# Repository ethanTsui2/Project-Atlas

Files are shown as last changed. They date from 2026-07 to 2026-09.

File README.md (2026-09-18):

# Project Atlas

Project Atlas is a 5-DOF desktop robotic manipulator that I designed, 3D printed, assembled, wired, programmed, tested, and improved from scratch.

<p align="center">
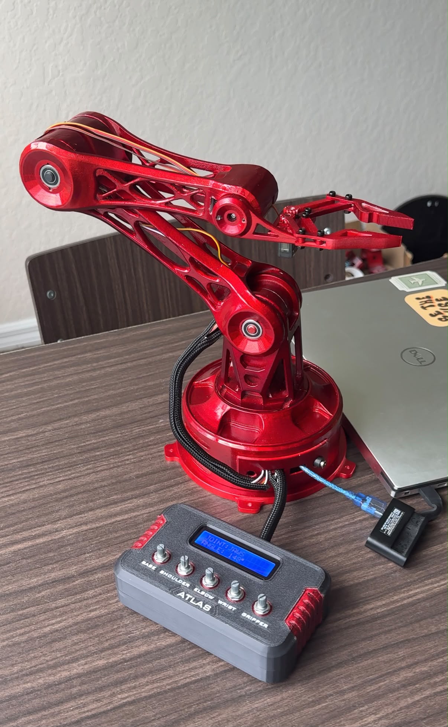
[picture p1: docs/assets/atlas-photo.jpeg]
Completed Project Atlas robotic arm
  
</p>

<p align="center">
  <a href="https://ethantsui2.github.io/Project-Atlas/"><b>Portfolio Page</b></a> |
  <a href="docs/assets/atlas-demo.mp4"><b>Demo Video</b></a> |
  <a href="CAD/"><b>CAD</b></a> |
  <a href="Documentation/Engineering-Analysis/"><b>Engineering Analysis</b></a>
</p>

---

## At a Glance

| Area | Final V1 setup |
|---|---|
| Mechanical design | SolidWorks, modular FDM-printed structure |
| Actuation | 3x MG995 + 2x MG90S servos |
| Control | Arduino Nano + PCA9685 PWM driver |
| User input | 5 potentiometers |
| User interface | 16x2 I2C LCD |
| Servo power | Regulated 5 V, 10 A external supply |
| Analysis | CAD mass properties, static torque analysis, SolidWorks FEA |
| Manufacturing | PLA FDM printing, mechanical assembly, painted finish |
| Status | **Atlas V1 prototype complete** |

## What I Worked On

- Designed the full arm layout and joint packaging in SolidWorks.
- Redesigned the upper arm, forearm, shoulder, wrist, gripper, base, and controller enclosure after physical testing.
- Added a printed slew-bearing base using **six steel balls** after the original base started tilting under load.
- Integrated five servo channels using an Arduino Nano and PCA9685.
- Built a five-potentiometer controller with a 16x2 LCD for live joint and angle feedback.
- Used CAD mass properties for a shoulder torque calculation and ran FEA on the upper arm.
- Finished the printed parts with filler primer, metallic silver, Dupli-Color Metalcast red, and gloss clear coat.

## Final Control System

The final firmware reads five potentiometers, averages eight analog readings per input, uses a 2 degree deadband to reduce unnecessary updates, drives the PCA9685 at 50 Hz, and displays the active joint angle on the LCD.

Firmware labels:

`BASE` | `ELBOW` | `WRIST` | `PIVOT` | `JAWS`

[View firmware](Firmware/)

## Engineering Highlights

### Mechanical iteration
The physical build exposed problems that were not obvious in CAD. The main ones were base tilting, forearm interference, cable pinching, servo-horn interference, wrist clearance, and gripper packaging. I went back into the CAD and changed the design around those issues instead of forcing the first version to work.

### Analysis before fabrication
Before the final build, I used SolidWorks mass properties, a static shoulder torque calculation, and a structural FEA study to check the design and better understand where the main loads were coming from.

[View engineering analysis](Documentation/Engineering-Analysis/)

### Build and integration
Atlas was built as a complete working prototype, not just a CAD model. The final system combines the printed structure, bearings, wiring, external servo power, embedded control, a separate controller enclosure, and the final painted finish.

[View build notes](Documentation/Build-Notes.md)

---

## Repository Guide

| Folder / document | What it contains |
|---|---|
| [`CAD/`](CAD/) | Final SolidWorks package, STL exports, slew-bearing files, and assembly views |
| [`Design-Evolution/`](Design-Evolution/) | The main versions of Atlas and the problems that led to each redesign |
| [`Documentation/Engineering-Analysis/`](Documentation/Engineering-Analysis/) | Torque analysis, FEA, material assumptions, and CAD mass properties |
| [`Documentation/BOM.md`](Documentation/BOM.md) | Hardware, materials, and documented project purchases |
| [`Documentation/Build-Notes.md`](Documentation/Build-Notes.md) | Manufacturing, assembly, slew bearing, electronics integration, and finishing |
| [`Electronics/`](Electronics/) | Control architecture, wiring, and pin assignments |
| [`Firmware/`](Firmware/) | Final control code and earlier development sketches |
| [`docs/`](docs/) | GitHub Pages site, resume, photo, and demo video |

## Final CAD Package

The final mechanical files are in [`CAD/Final-Package/`](CAD/Final-Package/), with the base bearing files in [`CAD/Slew-Bearing/`](CAD/Slew-Bearing/). I kept the original SolidWorks filenames so the assembly references are not broken.

[View CAD documentation](CAD/)

## Scope

Atlas V1 is a working engineering prototype. The torque calculation and FEA were design checks used during development. I have not listed payload, backlash, accuracy, or repeatability values because I did not run a controlled test for those yet.

---

## Development Process

**Requirements -> CAD -> Analysis -> 3D Printing -> Assembly -> Electronics -> Firmware -> Testing -> Redesign**

The biggest thing I learned from this project was how much changes once a design leaves CAD. Most of the useful improvements came from building it, finding what did not work, and going back to fix it.

## License

This project is released under the [MIT License](LICENSE).

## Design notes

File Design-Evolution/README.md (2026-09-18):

# Atlas V1 Design Evolution

Atlas V1 did not come from one finished CAD model. I went through several design, print, assembly, test, and redesign cycles before getting to the final version.

The main things I kept trying to improve were **joint clearance, stiffness, mass distribution, serviceability, cable routing, printability, and base stability**.

---

## Stage 1 - First Prototype

The first version proved that the basic servo-driven arm layout and gripper could work.

**Problems I found**

- bulky printed links
- limited joint clearance
- difficult servo access
- too much material in some parts
- inconsistent interfaces between components
- not enough room for cable routing

Initial Atlas V1 prototype

**What I changed:** I kept the general concept, but decided the structure needed a full redesign before I built the final version.

---

## Stage 2 - Enclosed Concept

I also tried an enclosed-shell version to hide the servos and wiring and make the arm look cleaner.

I did not continue with it because it added:

- more printed mass
- more supports
- more material
- harder assembly
- harder maintenance
- worse access to servos and fasteners

Atlas V1 enclosed-shell concept

**What I changed:** I moved away from a closed shell and focused on an open, modular structure instead.

---

## Stage 3 - Lightweight Modular Redesign

The next version used open structural rails, internal ribs, modular servo housings, split printed parts, and better access around the joints.

This improved:

- printability
- component access
- cable routing
- assembly flexibility
- mass distribution
- overall appearance

Atlas V1 lightweight modular redesign

**What I changed:** this became the main structure I used for the physical prototype.

---

## Stage 4 - Physical Test Revisions

Once I started assembling and testing the arm, I found problems that were much harder to notice in CAD.

The main ones were:

- the base tilting under the arm load
- forearm interference and restricted movement
- cable pinching
- servo-horn interference
- limited wrist and gripper clearance
- awkward access to some joints and fasteners

The biggest change was the base. I added a **printed slew bearing using six steel balls** so the rotating structure had its own mechanical support instead of relying mainly on the servo output shaft.

I also revised the forearm, servo interfaces, wiring space, and surrounding geometry after checking the real range of motion.

---

## Stage 5 - Completed Atlas V1

The final build uses:

- 3x MG995 servos for the larger arm joints
- 2x MG90S servos for the lighter end-effector functions
- printed structural links and modular housings
- a bearing-supported rotating base
- revised forearm and joint clearances
- managed cable routing
- a separate five-potentiometer controller enclosure
- a 16x2 LCD
- a metallic red painted finish

This is the final CAD assembly after the last round of physical-test revisions.

<p align="center">
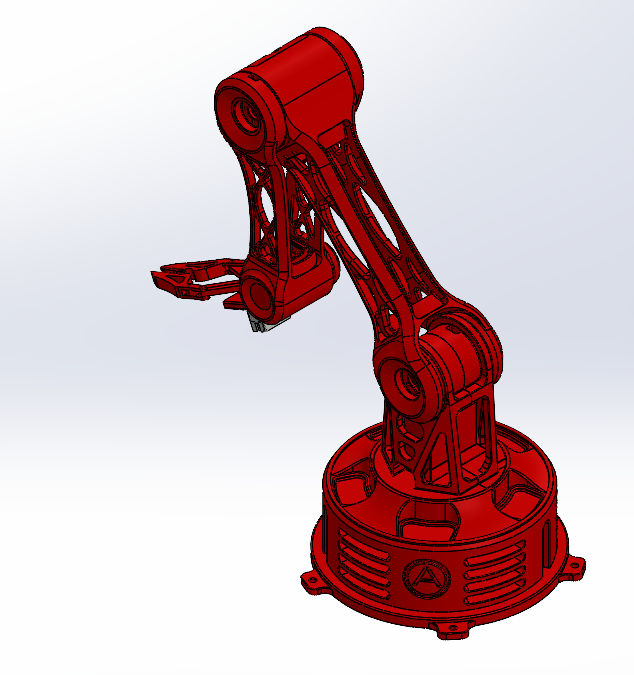
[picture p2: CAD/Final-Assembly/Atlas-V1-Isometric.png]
Final Atlas V1 CAD assembly
  
</p>

The finished physical prototype is shown below.

<p align="center">
  Completed Project Atlas V1
</p>

---

## Main Things I Learned

- Checking the full assembly matters more than checking parts one at a time.
- Weight farther from the shoulder has a much bigger effect on torque.
- Servo access, screw access, and cable routing need to be planned before printing.
- The servo shaft should not be the only structural support for a loaded rotating base.
- Physical prototypes expose tolerance, interference, stiffness, and routing problems that are easy to miss in CAD.
- A design can still look clean without adding a lot of extra material.

## Final Status

**Atlas V1 is complete as a functional physical prototype.**

I kept these earlier stages in the repo because they show how the project actually developed and why the final design looks the way it does.

For the final manufacturing and assembly details, see [Build Notes](../Documentation/Build-Notes.md).

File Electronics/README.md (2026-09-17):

# Atlas V1 Electronics

The final Atlas V1 control system uses an **Arduino Nano** to read the controls, a **PCA9685** to drive the servos, five potentiometers for manual joint control, and a **16x2 I2C LCD** for feedback.

## System Architecture

```text
5 potentiometers -> Arduino Nano -> PCA9685 -> 5 servos
                         |
                         -> I2C LCD

5 V / 10 A external supply -> PCA9685 servo rail
```

## Final Hardware

| Component | Function |
|---|---|
| Arduino Nano | Reads controls and runs the joint-control logic |
| PCA9685 | Generates PWM for five servo channels |
| 5 potentiometers | Manual joint input |
| 16x2 I2C LCD | Displays joint name and commanded angle |
| 3x MG995 | Higher-load arm joints |
| 2x MG90S | Lighter end-effector functions |
| 5 V, 10 A regulated supply | Dedicated servo power |

## Power Setup

- **Arduino Nano:** powered through USB
- **PCA9685 VCC:** 5 V logic supply from the Nano
- **PCA9685 V+:** external regulated 5 V servo supply
- **Servos:** powered from the PCA9685 V+ rail
- **Ground:** Nano, PCA9685, LCD, and external supply share a common ground

The servos are not powered directly from the Arduino Nano.

## I2C Bus

The PCA9685 and LCD share the Nano's I2C bus:

- A4 - SDA
- A5 - SCL

They use different I2C addresses, so both devices can use the same SDA and SCL lines.

## Wiring Documentation

- [Connection tables and pin assignments](wiring.md)
- [Arduino Nano / potentiometer diagram](./Arduino%20Nano%20and%20potentiometer%20wiring.png)
- [PCA9685 servo wiring diagram](./PCA9685%20servo%20wiring.png)

## Firmware

The final sketch averages the potentiometer readings, uses a 2 degree deadband, sends 50 Hz servo commands through the PCA9685, and updates the LCD when a joint command changes.

[View firmware](../Firmware/)

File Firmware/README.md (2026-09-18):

# Project Atlas Firmware

This folder contains the final Atlas V1 control sketch plus a few earlier programs I kept for reference.

## Final Control Firmware

**Location:** [`Final_Control/Atlas_Final_Control.ino`](./Final_Control/Atlas_Final_Control.ino)

The final controller uses an Arduino Nano, PCA9685 PWM driver, five potentiometers, and a 16x2 I2C LCD.

### What the final sketch does

- reads five analog control inputs
- averages **8 samples** per potentiometer reading
- maps each input to a **0-180 degree** command
- uses a **2 degree deadband** to reduce unnecessary servo updates
- drives five PCA9685 channels at **50 Hz**
- uses a pulse-width range of **650-2350 us**
- displays the active joint and angle on the LCD
- prints joint updates to the serial monitor for debugging

### Final input / channel map

| Potentiometer | Nano pin | PCA9685 channel | Firmware label |
|---|---|---|---|
| 1 | A0 | 0 | BASE |
| 2 | A1 | 1 | ELBOW |
| 3 | A2 | 2 | WRIST |
| 4 | A3 | 3 | PIVOT |
| 5 | A6 | 4 | JAWS |

## Required Arduino Libraries

- `Wire`
- `Adafruit PWM Servo Driver Library`
- `hd44780`
- `hd44780_I2Cexp`

## Development Sketches

I kept the earlier programs because they show how the controls developed from basic component testing into the final controller.

| Folder | Purpose |
|---|---|
| `basic-servo-control/` | Early PCA9685 and servo testing |
| `Manual_Control_v1/` | Earlier manual-control version |
| `Final_Control/` | Final V1 controller with averaging, deadband, and LCD feedback |

## Control Architecture

```text
Potentiometers -> Arduino Nano -> PCA9685 -> Servos
                         |
                         -> I2C LCD
```

The servos use a separate regulated 5 V supply. The Nano, PCA9685, LCD, and external supply share a common ground.

See [Electronics](../Electronics/) for the wiring and power setup.

## Scope

Atlas V1 uses direct manual joint control. It does not include closed-loop joint feedback, inverse kinematics, trajectory planning, or automatic motion sequencing.

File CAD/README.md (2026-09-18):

# Atlas V1 CAD

This folder contains the final mechanical design files for Project Atlas V1.

## Quick Access

- [`Final-Package/`](./Final-Package/) - final SolidWorks parts, assembly, and STL exports
- [`Slew-Bearing/`](./Slew-Bearing/) - printed base slew-bearing files
- [`Final-Assembly/`](./Final-Assembly/) - current CAD screenshots of the final assembly
- [`Reference_Components/`](./Reference_Components/) - servo reference geometry used in the CAD
- [`Final-CAD-Manifest.md`](./Final-CAD-Manifest.md) - file list for the final package

## Final Assembly Views

These are the most up-to-date CAD screenshots of the finished Atlas V1 assembly.

<table>
  <tr>
    <td align="center"><b>Isometric</b><br></td>
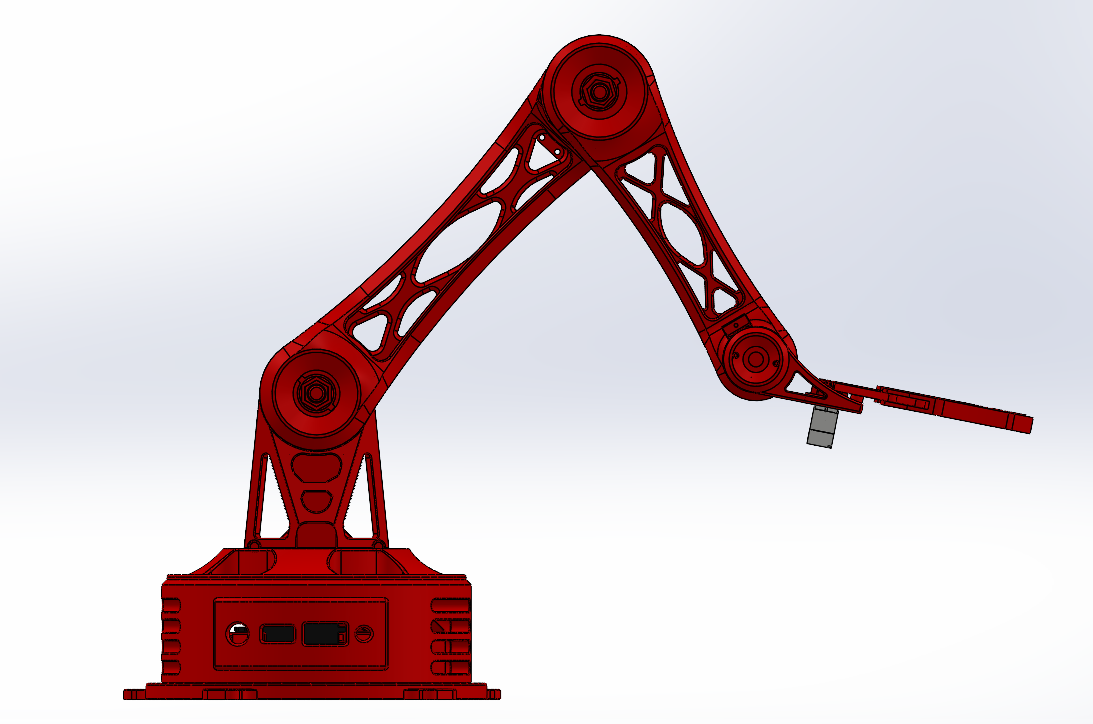
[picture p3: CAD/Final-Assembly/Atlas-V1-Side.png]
    <td align="center"><b>Side</b><br></td>
  </tr>
  <tr>
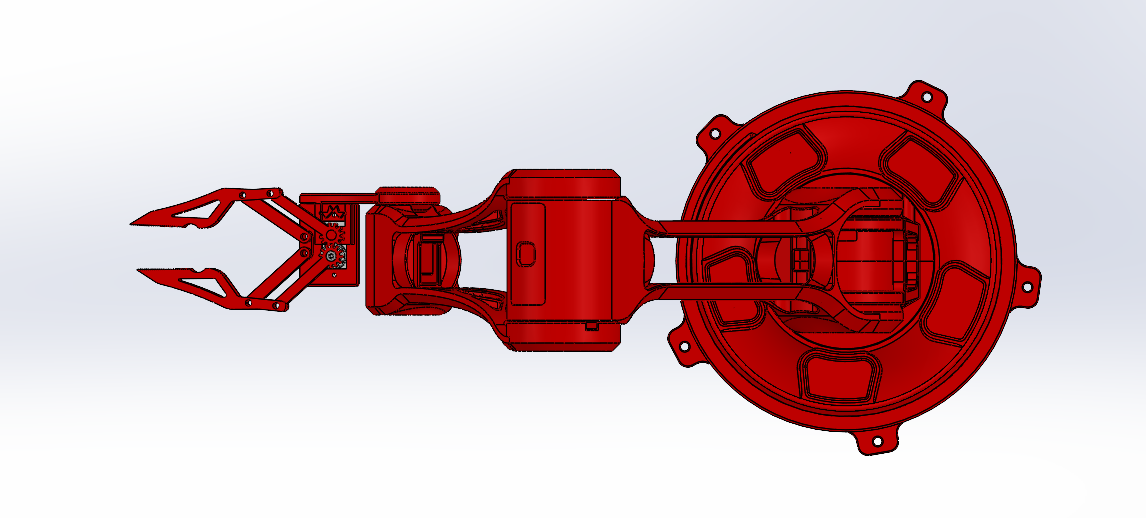
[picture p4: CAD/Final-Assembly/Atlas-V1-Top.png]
    <td align="center"><b>Top</b><br></td>
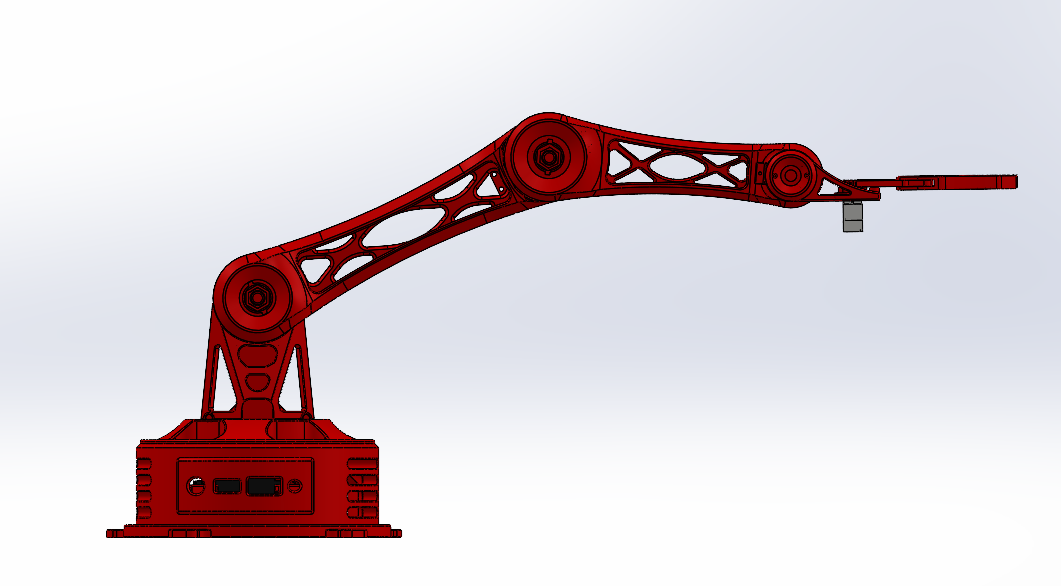
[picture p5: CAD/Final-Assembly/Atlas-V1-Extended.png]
    <td align="center"><b>Extended</b><br></td>
  </tr>
</table>

## Final Mechanical Setup

| Subsystem | Final approach |
|---|---|
| Base | Printed housing with six-ball slew-bearing support |
| Shoulder / main joints | MG995-driven modular printed structure |
| Upper arm | Lightweight ribbed PLA link |
| Forearm | Revised printed forearm with more clearance and routing space |
| Wrist / gripper | MG90S-driven end-effector assembly |
| Controller | Separate printed enclosure for five potentiometers and a 16x2 LCD |
| Manufacturing | SolidWorks source files with STL exports for printed parts |

## Final CAD Package

The final CAD is stored in [`Final-Package/`](./Final-Package/). This is the version that matches the completed build and includes the arm links, shoulder mounts, base housing, wrist and gripper parts, bearing interfaces, and controller enclosure.

The separate [`Slew-Bearing/`](./Slew-Bearing/) folder contains the base bearing geometry. The finished bearing uses **six steel balls**.

I kept the original SolidWorks filenames because renaming referenced parts outside SolidWorks can break the assembly.

## Main Design Priorities

The final design focused on:

- joint clearance
- reducing printed mass without making the links too flexible
- access to servos and fasteners
- better base support
- cable-routing space
- parts that could be printed separately and replaced if needed
- keeping the mechanical style consistent across the arm

For the main redesigns and the problems that caused them, see [Design Evolution](../Design-Evolution/README.md).

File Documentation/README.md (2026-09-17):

# Project Atlas Documentation

This folder contains the supporting engineering documentation for the completed Atlas V1 prototype.

I split the documentation into a few focused sections so it is easy to skim, but the technical details are still there if someone wants to go deeper.

## Documentation Map

| Document | What it covers |
|---|---|
| [Engineering Analysis](./Engineering-Analysis/README.md) | Material assumptions, CAD mass properties, shoulder torque, and upper-arm FEA |
| [Bill of Materials](./BOM.md) | Hardware, materials, and documented project purchases |
| [Build Notes](./Build-Notes.md) | Manufacturing, assembly, slew-bearing redesign, controller, wiring, and surface finishing |

## Related Project Sections

- [CAD](../CAD/) - final mechanical files and assembly views
- [Design Evolution](../Design-Evolution/) - the major versions and problems that led to redesigns
- [Electronics](../Electronics/) - control architecture and wiring
- [Firmware](../Firmware/) - final control code and earlier test sketches
- [Portfolio Site](https://ethantsui2.github.io/Project-Atlas/) - quick overview, resume, photo, and demo video

I left out generic workshop tools and other routine items unless they directly affected the design or build.

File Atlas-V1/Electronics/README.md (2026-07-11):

## Electronics Architecture

The robotic arm uses an Arduino Nano to read five potentiometers. Servo commands are sent through I2C to a PCA9685 16-channel PWM controller.

The Arduino Nano handles logic and input processing, while a separate regulated 5 V, 10 A supply powers the servos. All grounds are connected together to provide a shared voltage reference.

### Signal Flow

Potentiometers → Arduino Nano analog inputs → I2C → PCA9685 → Servos

### Important Power Separation

- Arduino Nano: powered through USB
- PCA9685 VCC: powered by the Nano 5 V output
- PCA9685 V+: powered by the external 5 V supply
- Servos: powered only through the PCA9685 V+ servo rail
- Nano, PCA9685, and external supply share a common ground

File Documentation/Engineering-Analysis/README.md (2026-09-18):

# Atlas V1 Engineering Analysis

I completed these analyses before the final Atlas V1 build to check the main mechanical loads and make better design decisions before printing everything.

They are design checks, not certified performance ratings for the finished robot.

## Analysis Baseline

All of the analysis was done using a frozen copy of the Atlas V1 CAD assembly.

| Property | Value |
|---|---|
| Revision | Atlas V1 Analysis Baseline |
| CAD Software | SolidWorks |
| Printed Material | Anycubic PLA V3.0 |
| Purpose | Check material properties, mass properties, shoulder torque, and upper-arm structural behavior before manufacturing |

## Analysis Configuration

For the shoulder torque calculation, I used the maximum practical extension I could reach before collision in SolidWorks. I chose that position because it gave the largest practical moment arm in the analyzed geometry.

---

## 1. Material Assumptions

I created a custom SolidWorks material using values from the **Anycubic PLA V3.0 Technical Data Sheet**.

The material documentation includes:

- density
- elastic modulus
- Poisson's ratio
- strength properties
- modeling assumptions
- density verification

[View material assumptions](./Material-Assumptions.md)

---

## 2. CAD Mass Properties

I extracted mass, volume, and center-of-mass data from SolidWorks for the main modeled components.

[View mass-property inventory](./Mass-Properties.md)

---

## 3. Static Shoulder Torque Analysis

I used the CAD mass properties and a static moment calculation to estimate the shoulder torque requirement.

### Key Results

| Quantity | Value |
|---|---:|
| Required shoulder torque | **1.047 N·m (10.67 kg·cm)** |
| Deegoo-FPV MG995 specified stall torque at 6 V | **13.00 kg·cm** |
| Static utilization | **82.1%** |
| Remaining static torque margin | **17.9%** |

Based on this calculation, the MG995 was theoretically capable of holding the analyzed configuration under static loading with no external payload.

This calculation did not include dynamic loading, acceleration, friction, wiring, fasteners, manufacturing tolerances, or payload effects.

[View full torque report](./Atlas-V1-Static-Shoulder-Torque-Analysis.pdf)

---

## 4. Upper-Arm Static Structural FEA

I also ran a static structural study on the upper arm in SolidWorks Simulation.

### Key Results

| Quantity | Value |
|---|---:|
| Maximum von Mises stress | **25.31 MPa** |
| Maximum resultant displacement | **0.755 mm** |
| Maximum equivalent strain | **0.00450** |
| Critical stress region | **Shoulder mounting bore** |
| Nominal X-Y strength ratio | **1.90** |
| Nominal Z-direction strength ratio | **1.11** |

For the model, I fully constrained the shoulder mounting bore. The real joint has additional bearing and support structure, so I treated the FEA as a conservative design check instead of an exact prediction of the assembled arm.

[View full FEA report](./Atlas-V1-Link1-Static-Structural-Analysis.pdf)

---

## After the Analysis

After building Atlas, physical testing led to more changes around the base support, joint clearance, wiring, and packaging.

I kept the original analysis in the repo because it shows the reasoning I used before fabrication. Any future payload, backlash, accuracy, or repeatability numbers should come from physical testing rather than being estimated from these reports.

[Return to project overview](../../README.md)

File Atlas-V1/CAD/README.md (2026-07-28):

# Atlas V1 CAD

This folder contains the complete mechanical CAD design for **Project Atlas V1**, including the final assembly, reference components, and design resources used throughout development.

---

# Final Assembly

The current mechanical design is shown below.

## Isometric View

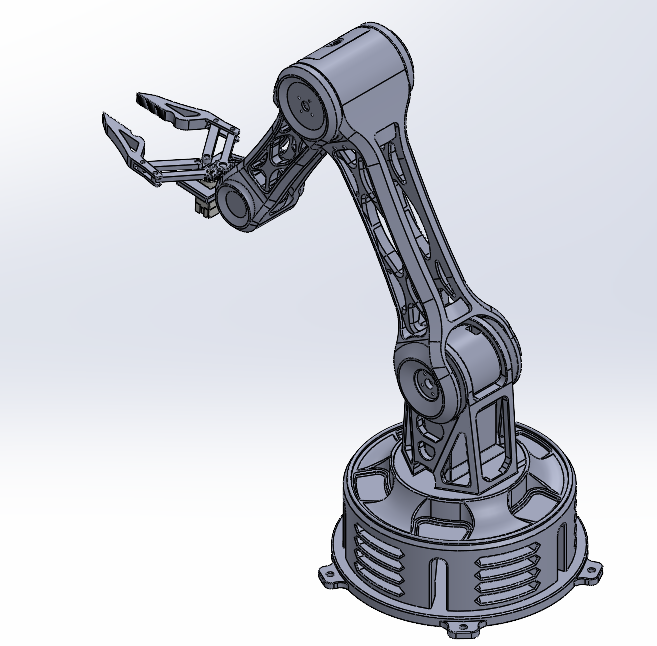
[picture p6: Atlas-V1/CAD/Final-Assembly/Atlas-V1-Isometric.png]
Atlas V1 Isometric


---

## Side View

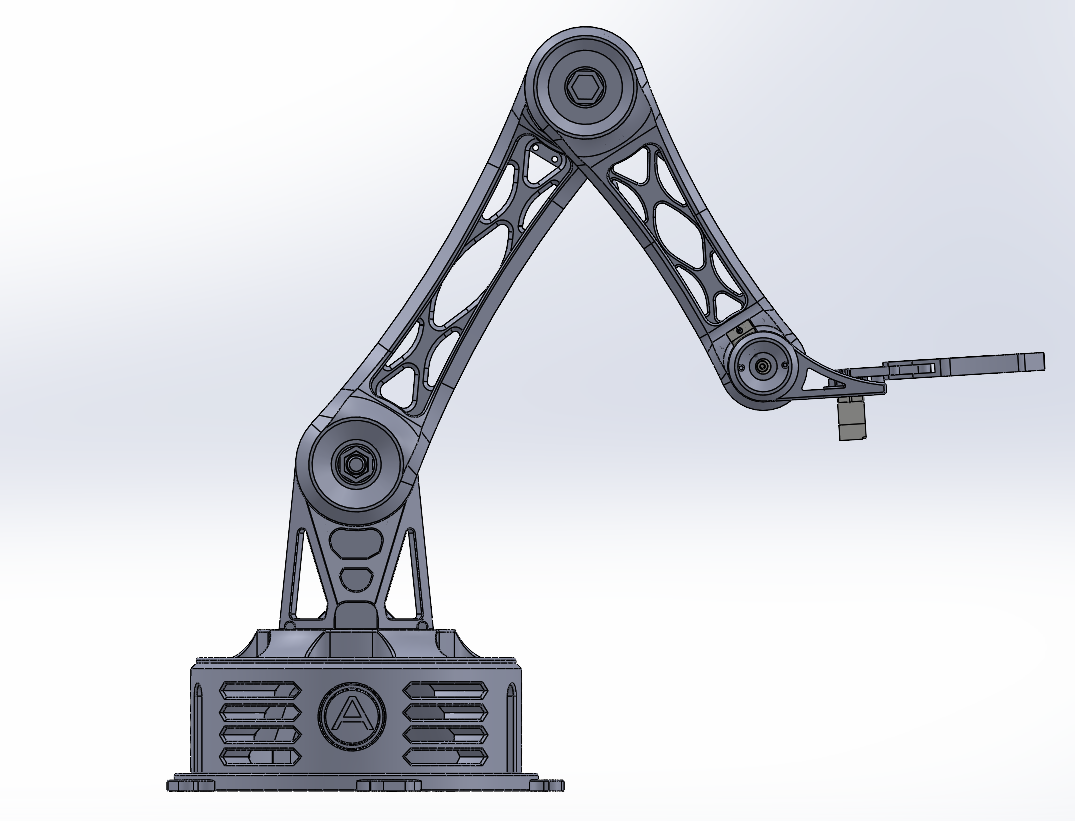
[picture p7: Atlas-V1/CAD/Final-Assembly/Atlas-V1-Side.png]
Atlas V1 Side


---

## Top View

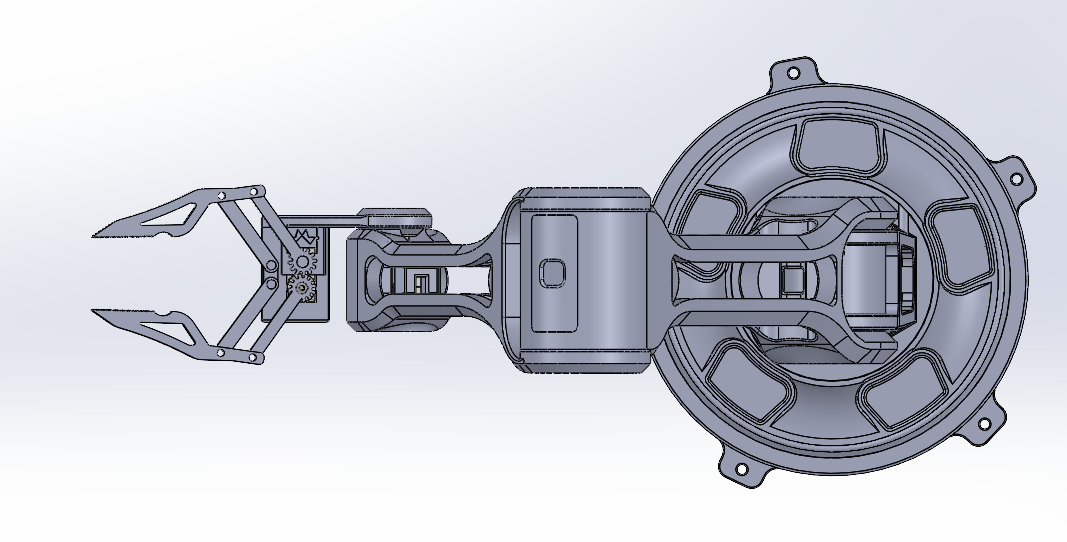
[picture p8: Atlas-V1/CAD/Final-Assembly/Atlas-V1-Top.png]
Atlas V1 Top


---

## Extended Configuration

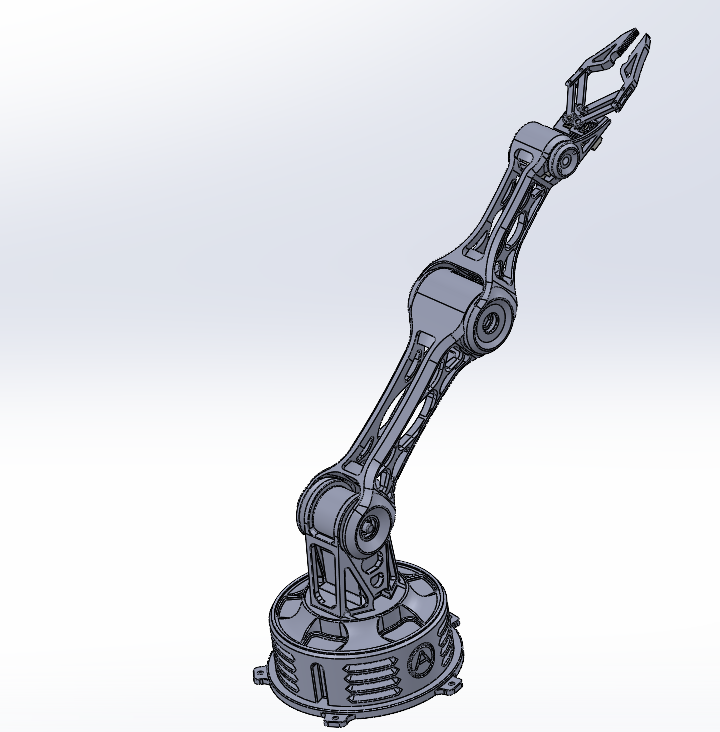
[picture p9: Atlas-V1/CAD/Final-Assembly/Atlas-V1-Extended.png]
Atlas V1 Folded


---

# Mechanical Specifications

| Component | Description |
|---|---|
| Degrees of Freedom | 5 DOF |
| Base Servo | MG995 |
| Shoulder Servo | MG995 |
| Elbow Servo | MG995 |
| Wrist Servo | MG90S |
| Gripper Servo | MG90S |
| CAD Software | SolidWorks |
| Manufacturing | FDM 3D Printing |

---

# Design Features

- Lightweight ribbed arm links
- Modular servo housings
- Split-print construction
- Internal cable routing
- Collision-checked assembly
- Heat-set insert mounting
- Serviceable servo covers
- Modular gripper assembly

---

# Folder Contents

```text
CAD/
├── Final-Assembly/
│   └── Final CAD screenshots
├── Source-Files/
│   └── Native SolidWorks parts and assemblies
├── Reference_Components/
│   ├── MG995/
│   └── MG90S/
└── README.md
│
└── README.md
```

```markdown
## Source Files

The `Source-Files` directory contains the complete SolidWorks assembly and its referenced components.

The files were exported using SolidWorks Pack and Go to preserve assembly references and reduce the chance of missing-part errors.

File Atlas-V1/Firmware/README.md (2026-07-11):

# Firmware

This folder contains the Arduino firmware developed for Project Atlas.

## Current Sketch

### Basic Servo Control

Location:

`basic-servo-control/basic-servo-control.ino`

This sketch was used to validate the initial electronics system.

It:

- Reads five potentiometers using the Arduino Nano
- Sends servo commands to the PCA9685 over I2C
- Controls five servo channels
- Maps potentiometer readings to servo angles from 0° to 180°
- Uses an external 5 V power supply for the servos

## Required Arduino Libraries

- Wire
- Adafruit PWM Servo Driver Library

## Hardware

- Arduino Nano
- PCA9685 16-channel PWM controller
- Five potentiometers
- Five servos
- External regulated 5 V power supply

## Current Status

The basic manual control system has been tested successfully.

## Planned Improvements

- Add joint-specific angle limits
- Add servo calibration offsets
- Add smoother motion
- Reduce sudden movement
- Add startup positioning
- Add emergency-stop behavior

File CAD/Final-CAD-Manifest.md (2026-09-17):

# Atlas V1 Final CAD Package Manifest

This is the file list for the final Atlas V1 CAD package. I kept the original filenames so the SolidWorks references are not broken.

## Repository Locations

- [`Final-Package/`](./Final-Package/) - main Atlas SolidWorks package and STL exports
- [`Slew-Bearing/`](./Slew-Bearing/) - final base slew-bearing files

## Main Atlas Package

### Assembly

- `v3 assembly.SLDASM`

### Major arm / base parts

- `AJM-01  → Atlas Joint Module (MG995)final.SLDPRT`
- `Atlas-V1-Upper-Arm.SLDPRT`
- `Atlas-V1-Upper-Arm.STL`
- `Atlas-V1-Forearm edit v2.SLDPRT`
- `Atlas-V1-Forearm edit v2.STL`
- `Atlas-V1-Shoulder-Mount-Left.SLDPRT`
- `Atlas-V1-Shoulder-Mount-Left.STL`
- `Atlas-V1-Shoulder-Mount-Right.SLDPRT`
- `Atlas-V1-Shoulder-Mount-Right.STL`
- `Atlas-V1-Base-Housing top.SLDPRT.SLDPRT`
- `Atlas-V1-Base-Housing top.STL`
- `Atlas-V1-Base-Housing bottom.SLDPRT.SLDPRT`
- `Atlas-V1-Base-Housing bottom.STL`
- `base housing.SLDPRT`

### Bearing / servo interface parts

- `bearing holder.SLDPRT`
- `bearing holder.STL`
- `bearing holder2.SLDPRT`
- `bearing holder2.STL`
- `bearing holder link 2.SLDPRT`
- `circular servo horn.SLDPRT`
- `servo horn extender.SLDPRT`
- `servo horn extender.STL`
- `servo lid.SLDPRT`
- `servo lid.STL`

### Gripper / wrist parts

- `gripper gear link.SLDPRT`
- `gripper gear link.STL`
- `gripper gear link2.SLDPRT`
- `gripper gear link2.STL`
- `gripper jaw.SLDPRT`
- `gripper jaw.STL`
- `gripper link1.SLDPRT`
- `gripper link1.STL`
- `robotic gripper part.SLDPRT`
- `robotic gripper wrist.SLDPRT`
- `robotic gripper wrist.STL`

### Controller parts

- `control board.SLDPRT`
- `control pannel.SLDPRT`
- `control pannel.STL`
- `controller bottom.SLDPRT`
- `controller bottom.STL`
- `controller top.SLDPRT`
- `controller top.STL`

## Slew-Bearing Package

- `Outer Race.f3d`
- `Outer Race.stl`
- `Inner Race.stl`
- `Upper Inner Race.stl`
- `Lower Inner Race.stl`
- `Cage.stl`
- `Parametric+Slew+Bearing+v9.stl`

The finished base bearing uses **six steel balls**.

## File Handling Note

The final package is kept together with the original filenames. Renaming SolidWorks parts outside SolidWorks can break assembly references.

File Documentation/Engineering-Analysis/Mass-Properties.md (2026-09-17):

# Atlas V1 Mass Inventory

This table records the mass properties I pulled directly from SolidWorks for the main Atlas V1 components.

The values are based on the CAD model using the verified **Anycubic PLA V3.0** material. I used this data as the starting point for the center-of-mass, torque, and FEA work.

| Component | Material | Mass (g) | Volume (mm³) | COM X (mm) | COM Y (mm) | COM Z (mm) | Evidence |
|:---|:---:|---:|---:|---:|---:|---:|:---:|
| **Printed Components** |||||||||
| Base Housing | PLA | 664.33 | 535753.64 | -0.54 | 19.66 | 0.56 | [View](Images/Base-Housing-Mass-Properties.png) |
| Shoulder Structure | PLA |196.29 |158294.43 |0.00 |40.84 |-0.06 | [View](Images/Wrist-Structure-Mass-Properties.png)|
| Link 1 Structure | PLA | 283.81 | 228876.24 | 582.93 | 991.96 | 1316.60 | [View](Images/Link-1-Mass-Properties.png) |
| Link 2 Structure | PLA | 164.24 | 132452.17 | 0.00 | 72.44 | -34.82 | [View](Images/Link-2-Mass-Properties.png) |
| Complete End Effector | PLA |30.23 |24378.13 |410.32 | 894.39|1307.39 |[View](Images/End-Effector-Mass-Properties.png)|
| **Purchased Components** |||||||||
| Shoulder MG995 Servo | Manufacturer | 55 | | | | | |
| Elbow MG995 Servo | Manufacturer | 55 | | | | | |
| Wrist MG90S Servo | Manufacturer | 13.4 | | | | | |
| Gripper MG90S Servo | Manufacturer | 13.4 | | | | | |
| **Estimated Components** |||||||||
| Fasteners & Heat-Set Inserts | Steel / Brass | | | | | | |
| Wiring | Copper / PVC | | | | | | |
| Payload (Design Target) | Variable | | | | | | |

> **Note:** Printed component values came from SolidWorks using the verified Anycubic PLA material. Servo masses are based on manufacturer specifications.

## Mass Summary

| Category | Mass (g) |
|---|---:|
| Printed Components | **1338.90** |
| Servos | **136.80** |
| Estimated Hardware | - |
| Estimated Wiring | - |
| **Estimated Total Robot Mass** | **1475.70 + hardware** |

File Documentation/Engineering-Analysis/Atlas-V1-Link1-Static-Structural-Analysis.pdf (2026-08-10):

Atlas V1 Finite Element Analysis

Upper Arm (Link 1) — Conservative Static Structural Assessment

Project Atlas | SolidWorks Simulation | August 2026

### 1. Objective

A finite element analysis (FEA) was performed on the Atlas V1 upper arm (Link 1) using SolidWorks

Simulation. The purpose of the analysis was to evaluate the structural response of the 3D-printed component

under representative static loading and identify regions of elevated stress and deformation.

The analysis focused on:

- Von Mises stress
- Resultant displacement
- Equivalent strain
- Critical stress locations
- Influence of the shoulder support condition

The analysis uses a simplified conservative support configuration in which the shoulder mounting bore is fully

constrained. In the physical Atlas V1 assembly, the opposite side of the shoulder joint is additionally supported

by a bearing. This bearing support was intentionally excluded from the FEA model to maintain a simplified

conservative structural assessment.

### 2. Material Properties

The upper arm is designed to be manufactured from Anycubic PLA using fused-filament fabrication.

Material properties were obtained from the Anycubic PLA Technical Data Sheet, Version 3.0. The manufacturer

reports properties based on printed test specimens and notes that mechanical performance depends on print

orientation and processing conditions.

Property | Value
Density | 1.24 g/cm³
Young's Modulus (X-Y) | 2534 ± 85 MPa
Tensile Strength (X-Y) | 48 ± 5 MPa
Tensile Strength (Z) | 28 ± 2.4 MPa
Elongation at Break (X-Y) | 8 ± 1%
Bending Strength (X-Y) | 90 ± 3 MPa
Bending Modulus (X-Y) | 3360 ± 100 MPa

The SolidWorks Simulation model approximates the printed PLA component as a homogeneous material.

Actual FDM-printed PLA exhibits direction-dependent mechanical behavior due to layer orientation and

interlayer bonding. Therefore, the simulation results are treated as a first-order structural estimate rather than an

exact prediction of printed-part failure.

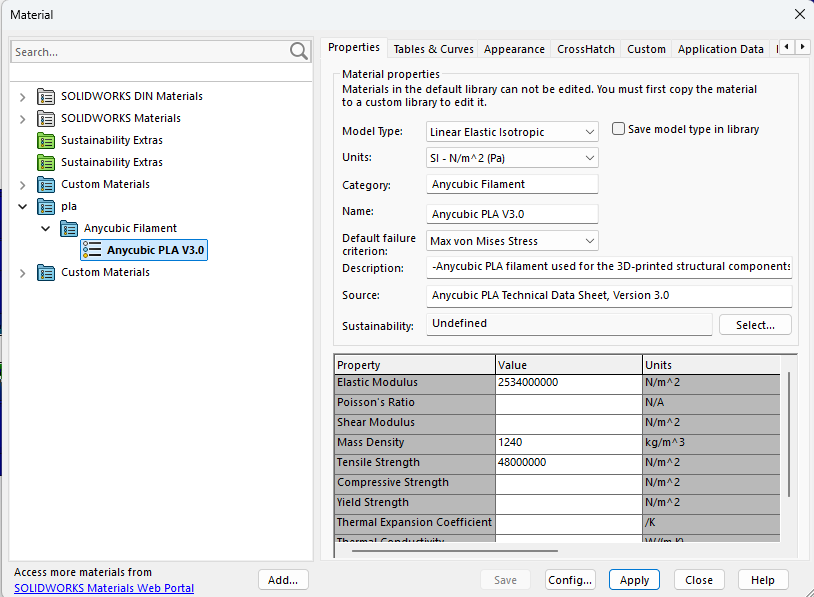
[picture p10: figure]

Figure 1: Anycubic PLA V3.0 Material Properties

### 3. Link 1 Static Structural Analysis

### 3.1 Analysis Configuration

A static structural study was created in SolidWorks Simulation to evaluate Link 1 under the loads transferred

from the downstream arm components.

The analysis represents the loading condition developed from the previously completed Atlas V1 static shoulder

torque analysis.

For the initial conservative study, the shoulder mounting bore was fully constrained. This simplifies the actual

joint connection and intentionally does not account for the additional support provided by the bearing located on

the opposite side of the assembled shoulder joint.

As a result, this study represents a simplified conservative structural model of Link 1. The actual assembly

includes additional bearing support at the shoulder joint; therefore, the boundary conditions used in this study

do not attempt to reproduce the complete joint contact behavior.

Applied Boundary Conditions

Boundary Condition | Value / Description
Study type | Static structural
Material | Anycubic PLA V3.0
Shoulder support | Fixed mounting bore
Gravity | 9.81 m/s²
Applied downstream force | 2.71 N
Applied moment | 0.221 N·m

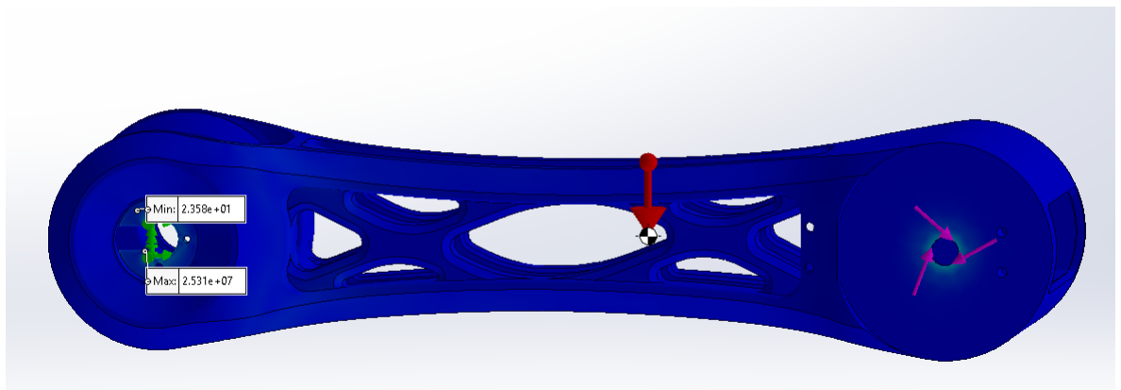
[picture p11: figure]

Figure 2: Conservative FEA Boundary Conditions

### 3.2 Mesh

A solid finite-element mesh was generated across the Link 1 geometry. The mesh captures the lightweight rib

structure, joint interfaces, mounting holes, fillets, and other geometric features that may influence the stress

distribution.

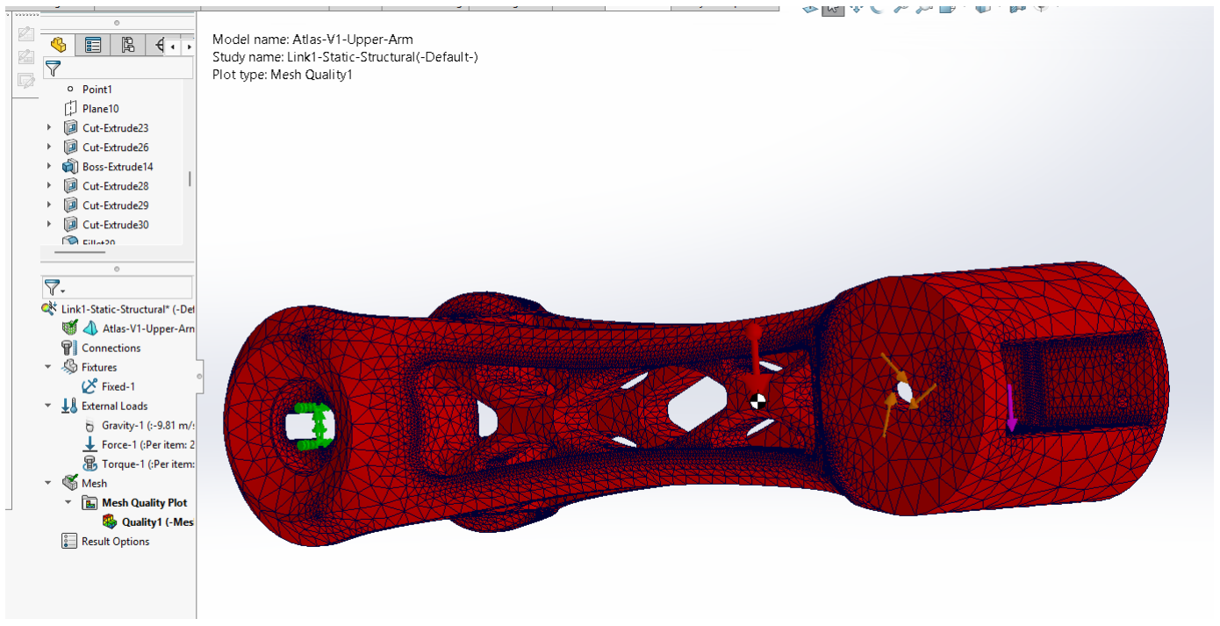
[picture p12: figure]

Figure 3: Link 1 Finite Element Mesh

A solid finite-element mesh was used to discretize the Link 1 geometry. The mesh was refined automatically

around smaller geometric features, fillets, mounting holes, and the lightweight rib structure. The resulting mesh

was considered sufficient for this preliminary structural assessment.

### 4. Conservative Analysis Results

### 4.1 Von Mises Stress

The static simulation predicted a maximum von Mises stress of 25.31 MPa. The maximum stress occurs locally

near the constrained shoulder mounting bore, where the applied loading is reacted through the fixed boundary

condition. Most of the upper-arm structure experiences substantially lower stress, indicating that the predicted

peak is localized around the shoulder connection rather than distributed throughout the lightweight rib structure.

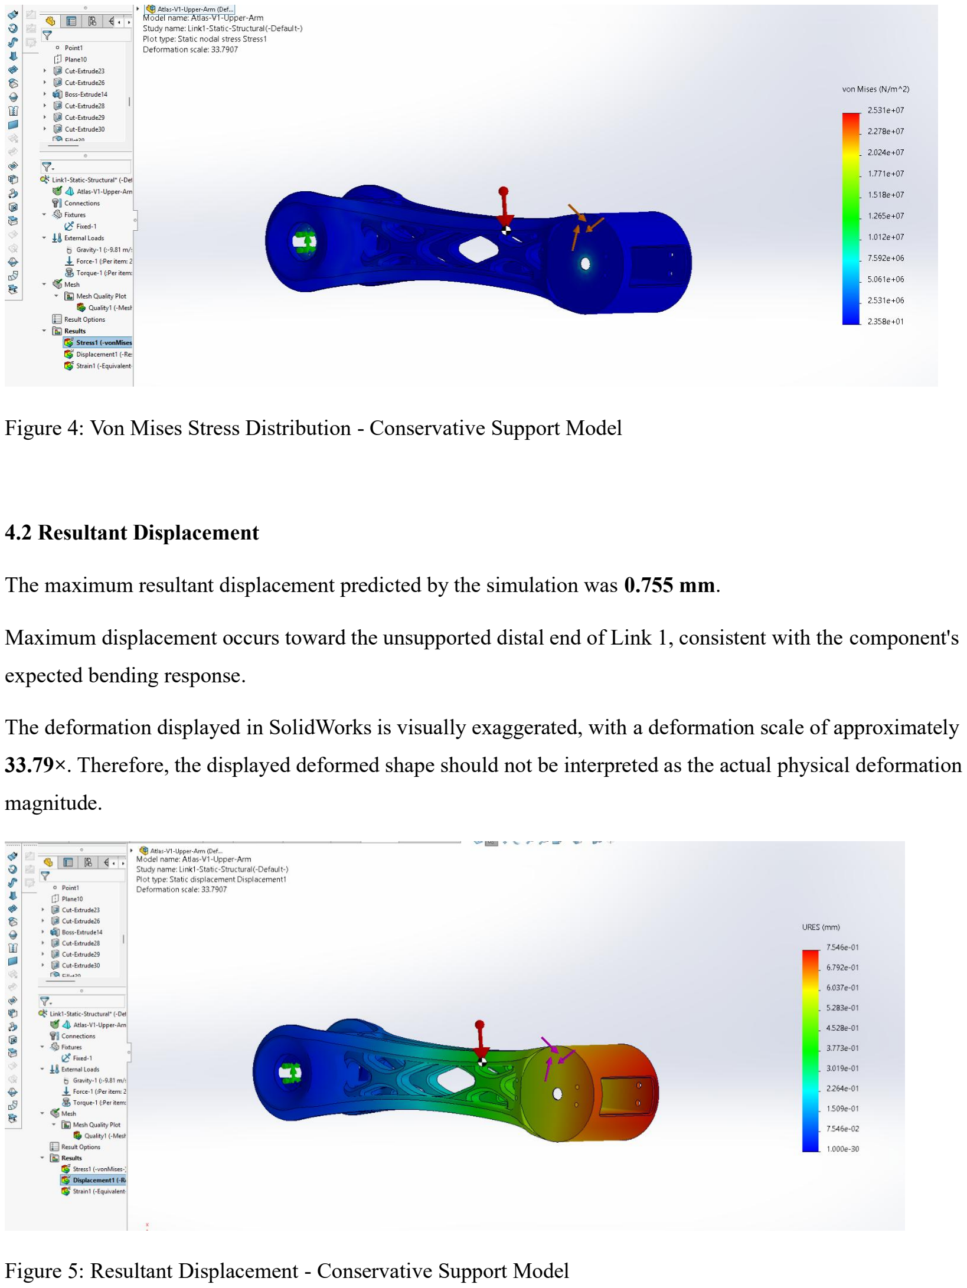
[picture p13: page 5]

Figure 4: Von Mises Stress Distribution - Conservative Support Model

### 4.2 Resultant Displacement

The maximum resultant displacement predicted by the simulation was 0.755 mm.

Maximum displacement occurs toward the unsupported distal end of Link 1, consistent with the component's

expected bending response.

The deformation displayed in SolidWorks is visually exaggerated, with a deformation scale of approximately

33.79×. Therefore, the displayed deformed shape should not be interpreted as the actual physical deformation

magnitude.

Figure 5: Resultant Displacement - Conservative Support Model

### 4.3 Equivalent Strain

The maximum equivalent strain predicted by the model was approximately 0.00450.

The strain distribution follows the general stress response of the structure, with elevated values concentrated

near the constrained joint region.

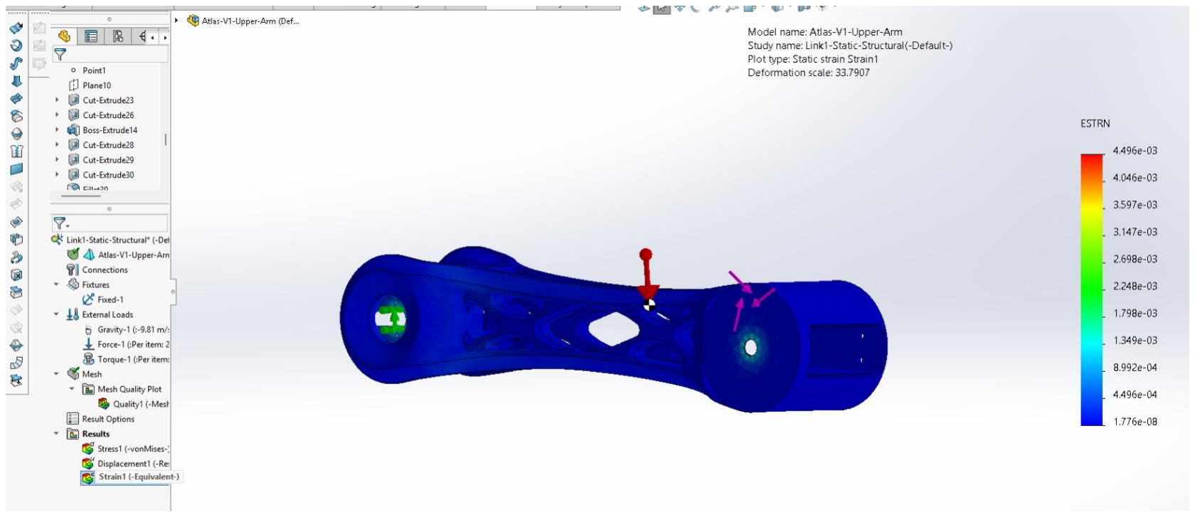
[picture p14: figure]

Figure 6: Equivalent Strain - Conservative Support Model

### 5. Conservative Analysis Summary

Result | Conservative Model
Maximum von Mises stress | 25.31 MPa
Maximum resultant displacement | 0.755 mm
Maximum equivalent strain | 0.00450
Critical stress region | Shoulder mounting bore
X-Y tensile strength | 48 ± 5 MPa
Nominal tensile-strength ratio | 1.90
Z-direction tensile strength | 28 ± 2.4 MPa
Nominal Z-direction strength ratio | 1.11

### 5.1 Nominal Tensile-Strength-to-Stress Ratio

Using the manufacturer's typical X-Y tensile strength:

X-Y Tensile Strength = 48 MPa

Maximum von Mises Stress = 25.31 MPa

The nominal tensile-strength-to-stress ratio was calculated as:

Strength Ratio = Tensile Strength / Maximum von Mises Stress

Strength Ratio = 48 MPa / 25.31 MPa

Strength Ratio = 1.90

Therefore, the nominal X-Y tensile-strength-to-stress ratio for the conservative simulation is approximately

1.90.

This value is not reported as a conventional yield-based factor of safety because the Anycubic PLA V3.0

technical data sheet does not provide a material yield strength. Additionally, the manufacturer's reported tensile

properties are dependent on print orientation and processing conditions.

### 5.2 Z-Direction Strength Consideration

The manufacturer reports a lower Z-direction tensile strength of:

Z-Direction Tensile Strength = 28 MPa

For comparison, the nominal Z-direction tensile-strength-to-stress ratio was calculated as:

Strength Ratio (Z) = Z-Direction Tensile Strength / Maximum von Mises Stress

Strength Ratio (Z) = 28 MPa / 25.31 MPa

Strength Ratio (Z) = 1.11

The resulting nominal Z-direction strength-to-stress ratio is approximately 1.11.

This value should not be interpreted as a conventional factor of safety because the SolidWorks model

approximates the printed PLA as a homogeneous isotropic material and does not explicitly model FDM layer

orientation or interlayer bonding.

However, the relatively small Z-direction strength ratio indicates that print orientation is an important

manufacturing consideration for Link 1. The component should therefore be printed in an orientation that

minimizes critical structural loading across the weaker interlayer direction where practical.

### 6. Conclusion

A static finite element analysis was performed on the Atlas V1 upper arm (Link 1) to evaluate its structural

response under representative loading derived from the Atlas V1 shoulder loading analysis.

The conservative model predicted a maximum von Mises stress of 25.31 MPa, a maximum resultant

displacement of 0.755 mm, and a maximum equivalent strain of approximately 0.00450. The highest predicted

stress was localized near the constrained shoulder mounting bore, while the majority of the lightweight rib

structure experienced substantially lower stress.

Comparison with the manufacturer's typical X-Y tensile strength of 48 MPa produced a nominal tensile-

strength-to-stress ratio of approximately 1.90. Comparison with the manufacturer's typical Z-direction tensile

strength of 28 MPa produced a lower nominal ratio of approximately 1.11, highlighting the importance of print

orientation for the FDM-manufactured component.

The analysis contains several simplifying assumptions. The printed PLA was modeled as a homogeneous,

linear-elastic, isotropic material, whereas actual FDM-printed PLA exhibits direction-dependent mechanical

behavior. The shoulder mounting bore was also modeled as fully constrained, while the physical Atlas V1

shoulder assembly includes additional bearing support on the opposite side of the joint. Dynamic loading,

impact, fastener preload, joint clearance, manufacturing defects, and detailed layer adhesion were not explicitly

modeled.

Within these assumptions, the conservative static analysis indicates that the Link 1 geometry is suitable to

proceed to prototype fabrication and physical validation. Final structural performance will be evaluated

through testing of the manufactured Atlas V1 assembly.

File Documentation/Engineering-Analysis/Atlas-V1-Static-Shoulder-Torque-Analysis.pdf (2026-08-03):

Atlas V1 Static Torque Analysis

### 1. Objective

The objective of this analysis is to determine whether the selected MG995 shoulder servo can statically support

the Atlas V1 robotic arm under its maximum collision-limited extension. The required shoulder holding torque

is calculated using SolidWorks mass properties and compared against the manufacturer's specified stall torque.

The analysis estimates the torque required at both the shoulder and elbow joints when the arm is positioned at

its maximum practical extension (collision-limited configuration). The calculated torque will then be compared

to the manufacturer's rated torque of the MG995 servo.

### 2. Assumptions

The following assumptions are made:

- Static analysis only (no acceleration).
- Gravity acts vertically downward.
- All printed components are modeled using Anycubic PLA V3.0 material.
- CAD mass properties obtained from SolidWorks are assumed accurate.
- Servo masses are taken from manufacturer specifications.
- Wiring, screws, bearings, and payload are neglected during the initial analysis.
- The arm configuration corresponds to the maximum extension achievable before self-collision.

### 3. Component Masses

Component | Mass (g) | Mass (kg)
Link 1 Printed Structure | 280.24 | 0.28024
Elbow MG995 Servo | 55 | 0.05500
Link 2 Printed Structure | 164.24 | 0.16424
Wrist MG90S Servo | 13.4 | 0.01340
Printed End Effector | 30.23 | 0.03023
Gripper MG90S Servo | 13.4 | 0.01340

### 4. Weight Calculation

Each component weight is calculated using

W = mg

where

- m= component mass (kg)
- g = 9.81 m/s

2

Weight Calculations

Link 1

W1 = 0.28024(9.81)

W1 = 2.749N

Elbow Servo

W2 = 0.055(9.81)

W2 = 0.540N

Link 2

W3 = 0.16424(9.81)

W3 = 1.611N

Wrist Servo

W4 = 0.0134(9.81)

W4 = 0.131N

Printed End Effector

W5 = 0.03023(9.81)

W5 = 0.297N

Gripper Servo

W6 = 0.0134(9.81)

W6 = 0.131N

Summary

Component | Mass (g) | Mass (kg)
Link 1 Printed Structure | 280.24 | 0.28024
Elbow MG995 Servo | 55 | 0.05500
Link 2 Printed Structure | 164.24 | 0.16424
Wrist MG90S Servo | 13.4 | 0.01340
Printed End Effector | 30.23 | 0.03023
Gripper MG90S Servo | 13.4 | 0.01340

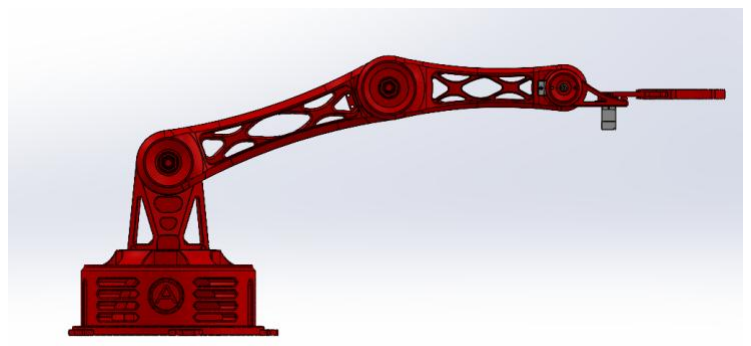
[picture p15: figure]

Figure 1: Fully Extended Arm

Figure 1 illustrates the loading assumptions used for the static analysis. Each component weight is represented

as a concentrated force acting through its center of mass.

FBD

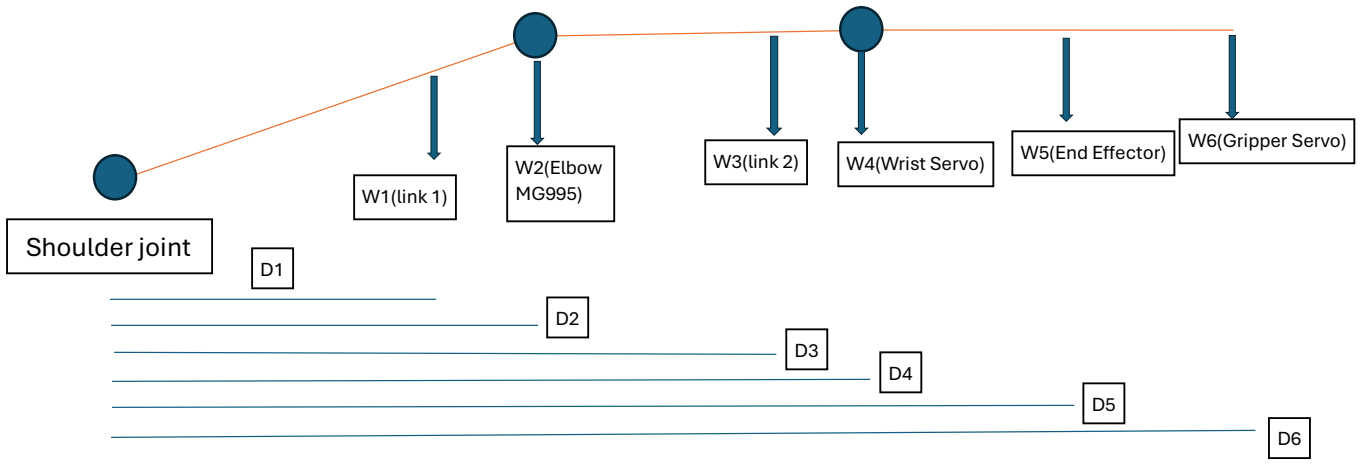
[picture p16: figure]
Shoulder joint; W1(link 1); W2(Elbow MG995); W3(link 2); W4(Wrist Servo); W5(End Effector); W6(Gripper Servo)

### 5. Determination of Moment Arms

The torque generated by each component depends on both its weight and the perpendicular distance from the

shoulder joint to its center of mass. These distances were determined directly from the SolidWorks assembly

using the maximum collision-limited extension of the Atlas V1 arm.

Each printed component was assigned the verified Anycubic PLA V3.0 material and its center of mass was

obtained using the SolidWorks Mass Properties tool. Manufacturer specifications were used for the servo

masses, while their center locations were approximated at the geometric centers of the servo bodies.

The maximum collision-limited extension was determined using the SolidWorks Collision Detection tool. Once

this configuration was reached, the shoulder joint was fixed to preserve the arm position while the remaining

measurements were obtained. This configuration is shown in Figure 1.

### 5.1 Link 1 Center of Mass

The Link 1 printed structure has a mass of 280.24 g.

The center of mass was obtained directly from SolidWorks using the Mass Properties tool. A reference

coordinate system was created at the shoulder axis to measure the horizontal distance from the shoulder joint to

the Link 1 center of mass.

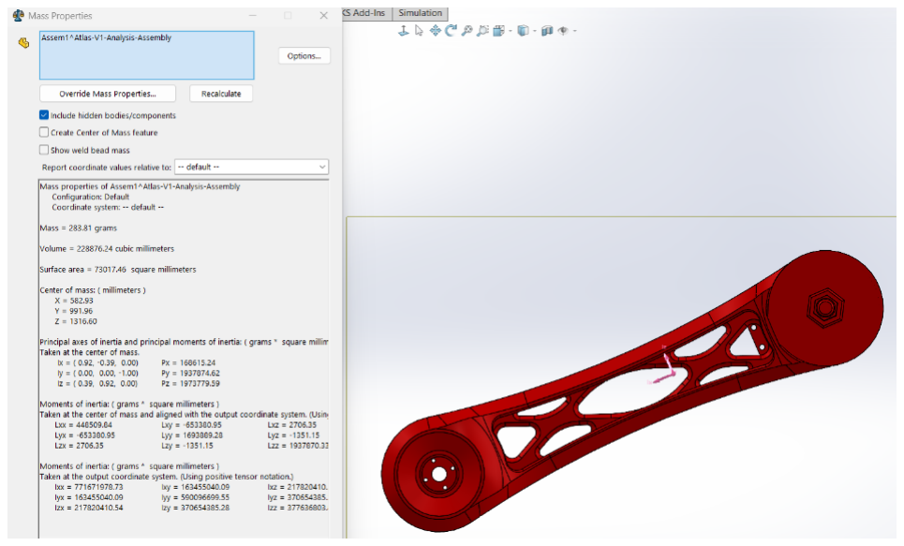
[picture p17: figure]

Figure 2: Link 1 Center of Mass and moment arm.

The maximum shoulder rotation was first determined using SolidWorks Collision Detection, allowing the arm

to rotate until the first point of self-interference was reached. This configuration represents the maximum

practical extension of Atlas V1 and was used as the worst-case loading condition for the static torque analysis.

After reaching this position, Link 1 was fixed to preserve the configuration. Construction centerlines were then

created through the shoulder and elbow joint axes, and the angle of Link 1 relative to the horizontal reference

was measured as 18.74°.

The center of mass of Link 1 is located 120.03 mm from the shoulder joint along the link centerline. Since

gravity acts vertically downward, only the horizontal projection of this distance contributes to the moment arm

about the shoulder joint. Therefore, the effective moment arm is calculated using

D1 = r1 cos θ1

where

- r1 = 120.03 mmis the distance from the shoulder axis to the Link 1 center of mass,
- θ1 = 18.74∘
is the measured angle between Link 1 and the horizontal.

Substituting the measured values,

D1 = (120.03)cos(18.74∘)

D1 = 113.68 mm

This horizontal distance is subsequently used in the calculation of shoulder joint torque.

### 5.2 Elbow Servo

The elbow MG995 servo is mounted directly at the end of Link 1.

Using the assembly geometry,

D2 = 189.50 mm

### 5.3 Link 2 Center of Mass

The Link 2 printed structure has a mass of 164.24 g.

The center of mass lies 72.44 mm beyond the elbow axis.

Therefore,

D3 = 189.50 + 72.44 = 261.94 mm

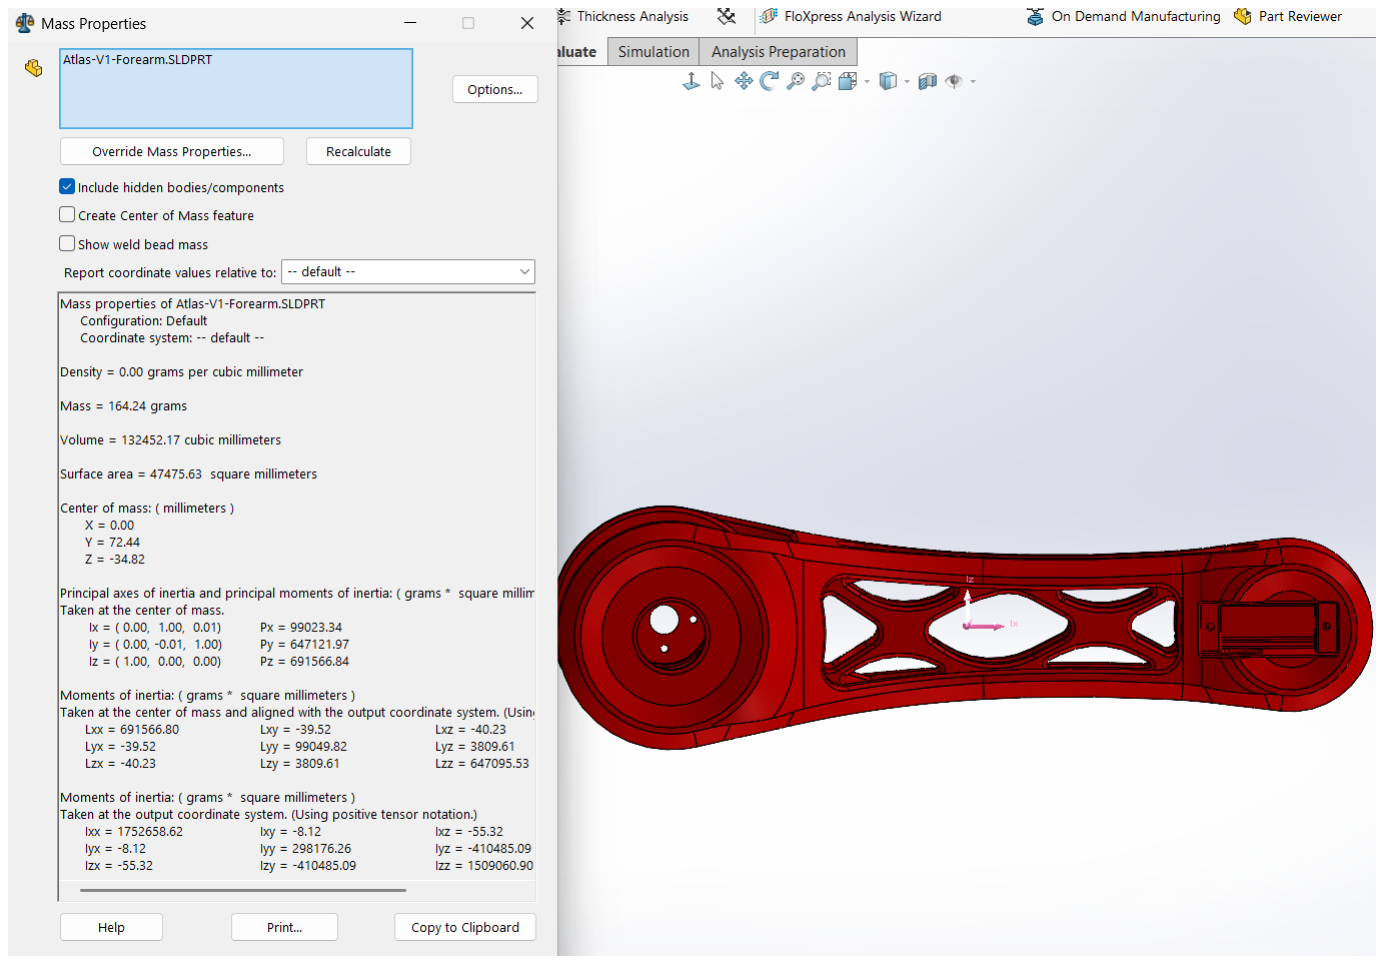
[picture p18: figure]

Figure 3: Link 2 Center of Mass and moment arm.

### 5.4 Wrist Servo

The wrist MG90S servo is located at the wrist joint.

Measured distance:

D4 = 339.26 mm

### 5.5 Printed End Effector

A local coordinate system was created with its origin at the wrist axis and the x-axis aligned with the gripper.

The SolidWorks Mass Properties tool reported

X = −50.73 mm

Only the magnitude is required for the torque calculation.

Therefore,

D5 = 339.26 + 50.73 = 389.99 mm

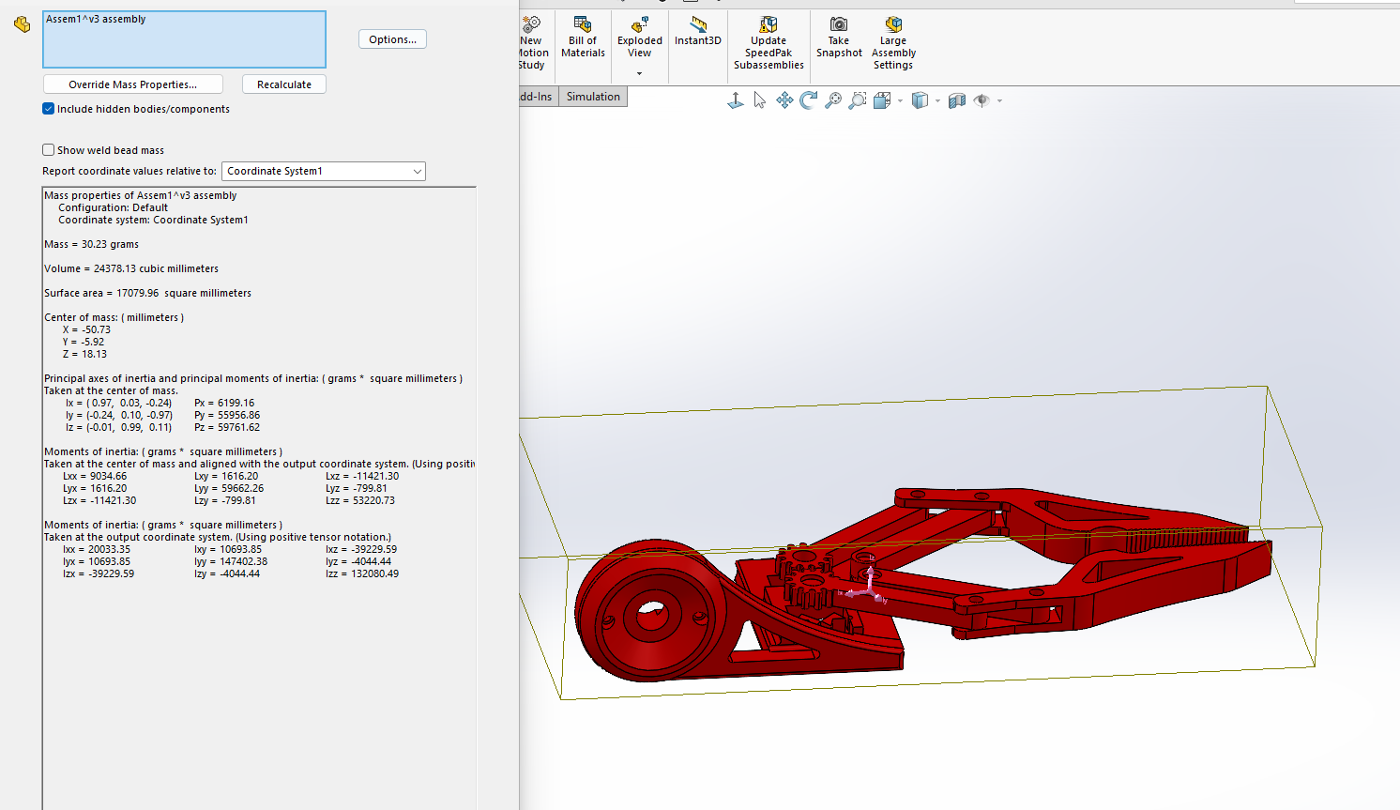
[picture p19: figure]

Figure 4: End Effector Center of Mass

### 5.6 Gripper Servo

The MG90S servo located within the gripper was measured directly in the assembly.

D6 = 378.10 mm

### 6. Shoulder Joint Static Torque Analysis

The static torque about the shoulder joint is obtained by summing the moment produced by each component.

For each component,

Wi = mig

and

τi = WiDi

where

- Wi
is the component weight,
- Di
is the horizontal distance from the shoulder axis to the component center of mass.

Link 1

Weight

W1 = (0.28024)(9.81) = 2.749 N

Moment arm

D1 = 0.11368 m

Torque

τ1 = (2.749)(0.11368) = 0.313 N ⋅ m

Elbow MG995

m2 = 0.055 kg
W2 = (0.055)(9.81) = 0.540 N

D2 = 0.18950 m
τ2 = (0.540)(0.18950) = 0.102 N ⋅ m

Link 2

m3 = 0.16424 kg
W3 = (0.16424)(9.81) = 1.611 N

D3 = 0.26194 m
τ3 = (1.611)(0.26194) = 0.422 N ⋅ m

Wrist Servo

m4 = 0.0134 kg
W4 = (0.0134)(9.81) = 0.1315 N

D4 = 0.33926 m
τ4 = (0.1315)(0.33926) = 0.0446 N ⋅ m

Printed End Effector

m5 = 0.03023 kg
W5 = (0.03023)(9.81) = 0.2966 N

D5 = 0.38999 m
τ5 = (0.2966)(0.38999) = 0.1157 N ⋅ m

Gripper Servo

m6 = 0.0134 kg
W6 = (0.0134)(9.81) = 0.1315 N

D6 = 0.37810 m
τ6 = (0.1315)(0.37810) = 0.0497 N ⋅ m

Total Shoulder Torque

Tsℎoulder = ∑τi

6

i=1
Tsℎoulder = 0.313 + 0.102 + 0.422 + 0.0446 + 0.1157 + 0.0497

Tsℎoulder = 1.047 N ⋅ m

Converting to the units commonly used for servos,

Tsℎoulder =

1.047
0.09807 = 10.67 kg ⋅ cm

### 7. Results

The calculated static torque required at the shoulder joint is

Tsℎoulder = 1.047 N ⋅ m

which is equivalent to

10.67 kg ⋅ m

Servo Capability Comparison

The shoulder actuator used in Atlas V1 is the Deegoo-FPV MG995 metal gear servo. According to the

manufacturer's published specification, the servo provides a stall torque of 13 kg·cm at 6 V.

The calculated static shoulder torque required by Atlas V1 is

Trequired = 10.67 kg ⋅ cm

Therefore,

10.67 < 13.00

The remaining static torque margin is

13.00 − 10.67 = 2.33 kg ⋅ cm

which corresponds to

2.33
13.00 × 100 = 17.9%

The analysis therefore indicates that the selected MG995 servo is capable of supporting Atlas V1 under static

loading without an external payload.

Discussion

The calculated shoulder torque represents the theoretical static holding torque required to support the Atlas V1

arm in its maximum collision-limited extension without any external payload.

This analysis assumes static equilibrium and neglects the effects of acceleration, friction, fasteners, wiring, and

manufacturing tolerances. Consequently, the calculated torque should be considered the minimum required

holding torque. In practical operation, additional torque margin is required to account for dynamic motion and

ensure reliable performance.

Quantity | Value
Required shoulder torque | 1.047 N·m
Required shoulder torque | 10.67 kg·cm
MG995 specified stall torque (6 V) | 13.00 kg·cm
Static utilization | 82.1%
Remaining margin | 17.9%

### 8. Conclusion

This analysis evaluated the static shoulder torque required to support the Atlas V1 robotic arm using SolidWorks

mass properties and classical free-body analysis.

The maximum static shoulder torque was calculated to be

Tsℎoulder = 1.047 N ⋅ m

which is equivalent to

10.67 kg ⋅ cm.

Comparison with the manufacturer's specified stall torque of 13 kg·cm at 6 V indicates that the selected

Deegoo-FPV MG995 servo is capable of supporting the Atlas V1 arm in its maximum collision-limited

configuration under static loading.

The calculated utilization is approximately 82%, leaving a static torque margin of approximately 18%.

Although adequate for static operation, this margin does not account for dynamic effects such as acceleration,

impact loading, payloads, friction, manufacturing tolerances, or long-term servo wear.

Future work will focus on:

- Static finite element analysis (FEA) of the printed components.
- Experimental validation using the assembled prototype.
- Dynamic torque analysis during motion.
- Evaluation of higher-performance actuators for future Atlas revisions.

References

1. Anycubic. PLA V3.0 Technical Data Sheet.
2. Dassault Systèmes. SOLIDWORKS Mass Properties Documentation.
3. Deegoo-FPV. MG995 Metal Gear Servo Motor Product Specifications (13 kg·cm stall torque at 6 V).

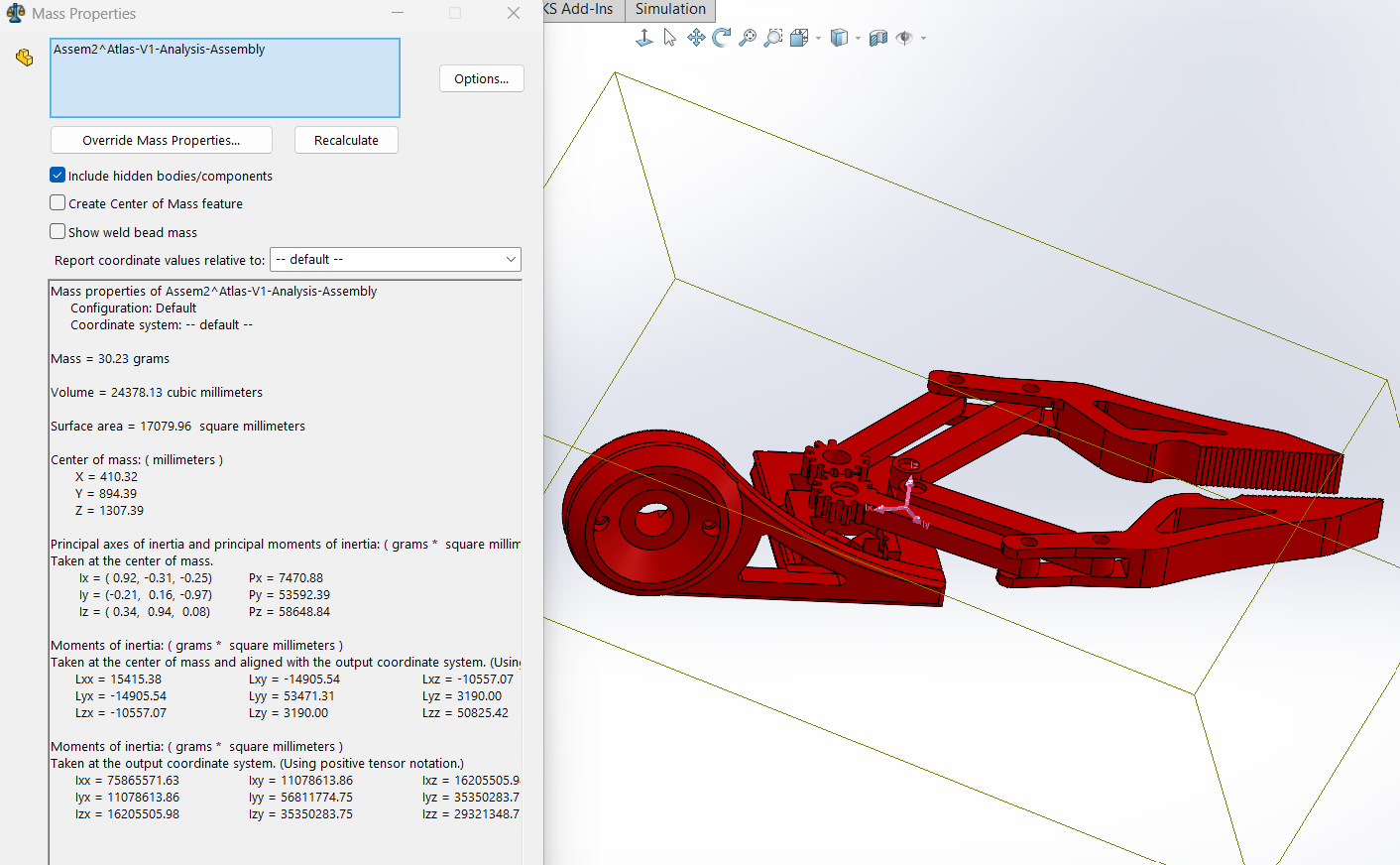
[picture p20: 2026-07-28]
Documentation/Engineering-Analysis/Images/End-Effector-Mass-Properties.png

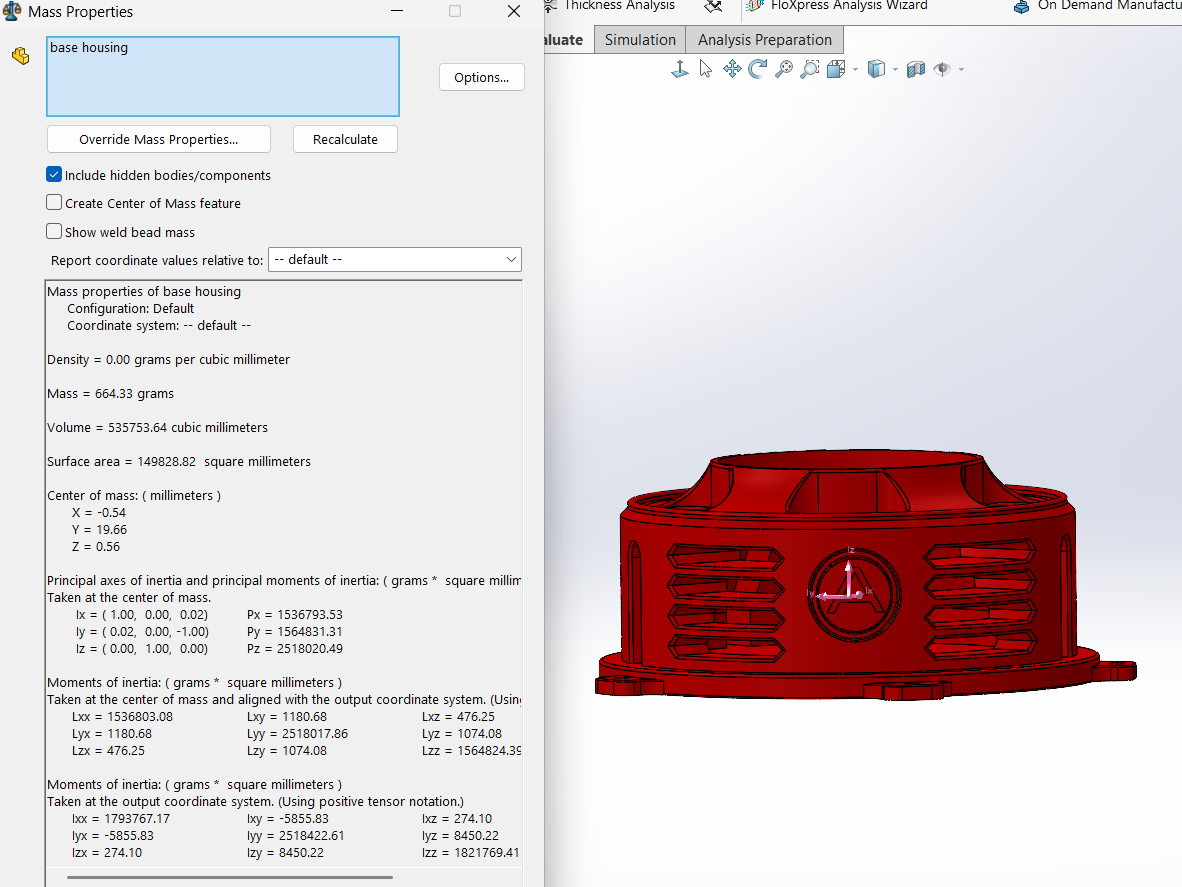
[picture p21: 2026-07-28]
Atlas-V1/Documentation/Engineering-Analysis/Images/.gitkeepBase-Housing-Mass-Properties.png

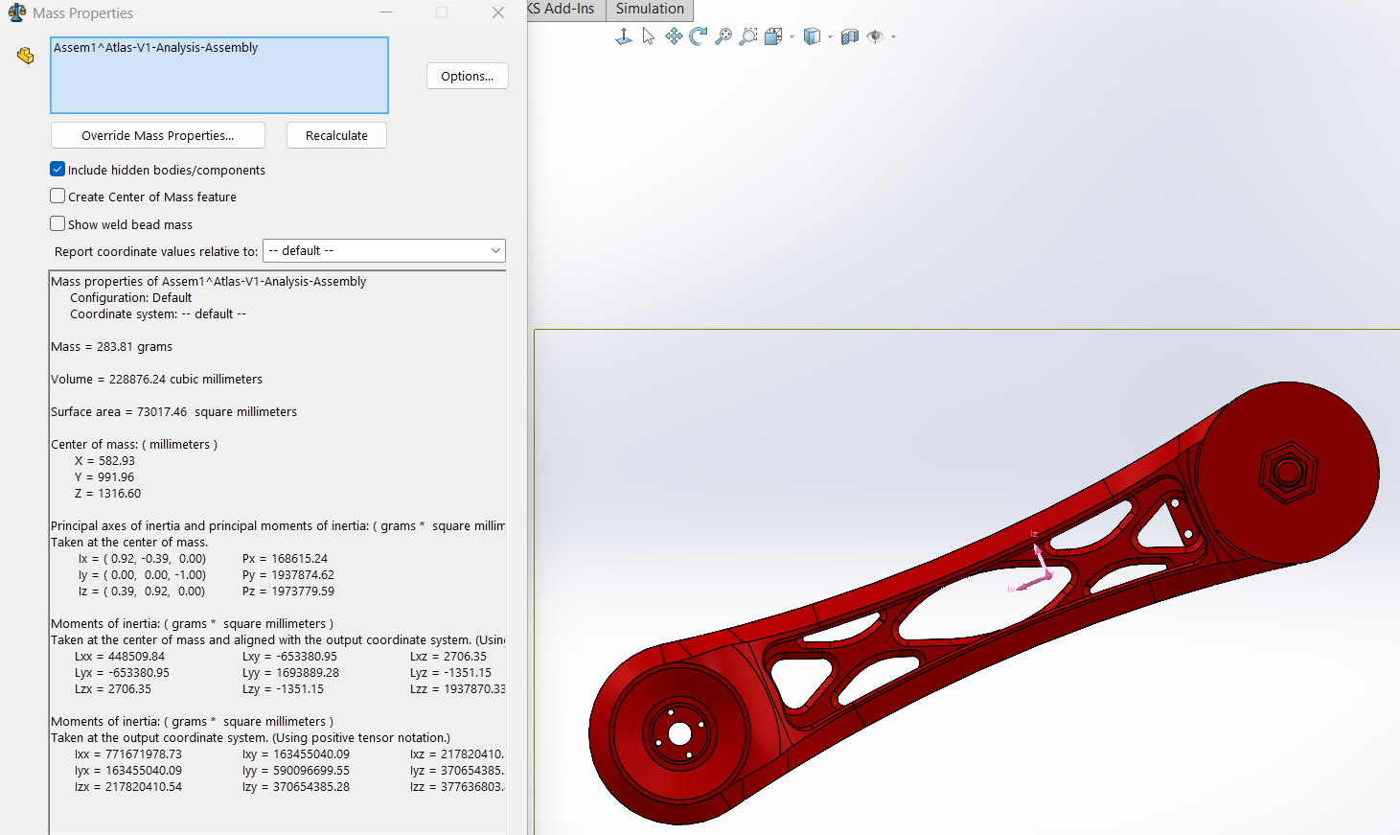
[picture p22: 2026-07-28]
Atlas-V1/Documentation/Engineering-Analysis/Images/.gitkeepLink-1-Mass-Properties.png

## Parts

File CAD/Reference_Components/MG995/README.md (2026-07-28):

# MG995 Servo Reference

The MG995 servo is used for the three main Atlas V1 joints:

- base rotation
- shoulder pitch
- elbow pitch

The reference model in this folder was used for:

- servo packaging
- mounting-hole placement
- joint-clearance checks
- horn alignment
- assembly interference analysis

## Important Note

MG995 dimensions can vary slightly between manufacturers. All printed mounting interfaces should be verified using the physical servos before full production printing.

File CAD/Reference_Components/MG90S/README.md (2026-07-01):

# MG90S Reference Model

This folder contains the MG90S servo reference CAD model used for Project Atlas.

## Source

The initial MG90S CAD model was created by Nicolas Corona and downloaded from GrabCAD.

Model: MG90S Micro Servo Motor – High Detail CAD Model (Internal Gears & Motor Included)

Author: Nicolas Corona

Source: GrabCAD

## Verification

Critical dimensions were checked in SolidWorks and compared against the physical MG90S servo before using the model for mechanical design.

## Use in Project Atlas

This model is used as a reference component for designing servo mounts, joints, and mechanical clearances.

All custom robotic arm components designed for Project Atlas are original work.

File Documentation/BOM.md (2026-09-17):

# Atlas V1 Bill of Materials

This BOM separates the parts and materials used in the finished prototype from things I bought during development but did not necessarily use in the final arm.

## Final Build - Core Hardware

| Item | Qty used | Role |
|---|---:|---|
| MG995 metal-gear servo | 3 | Higher-load arm joints |
| MG90S micro servo | 2 | Lighter end-effector functions |
| Arduino Nano | 1 | Main controller |
| PCA9685 16-channel PWM driver | 1 | Servo PWM generation over I2C |
| WH148-style potentiometer | 5 | Manual joint input |
| 16x2 I2C LCD | 1 | Joint / angle feedback |
| Regulated 5 V, 10 A power supply | 1 | External servo power |
| Flanged ball bearings (F688-2RS, 8x16x5 mm) | As required | Joint / rotating support |
| Precision steel balls | 6 | Printed slew-bearing base |
| Servo extension leads | As required | Servo wiring and routing |
| 22 AWG flexible wire | As required | Power / controller wiring |
| Assorted metric fasteners | As required | Mechanical assembly |

## Printed / Fabricated Components

The main structural and enclosure parts were FDM printed from the final CAD package, including:

- base housing
- shoulder and joint structure
- upper arm
- revised forearm
- wrist and gripper parts
- bearing holders and servo covers
- printed slew-bearing parts
- controller enclosure and panel

I bought both black and white Anycubic PLA during development. The final visible arm parts were painted after printing.

## Surface Finish

| Material | Purpose |
|---|---|
| Rust-Oleum 2-in-1 Filler & Sandable Primer | Fill print texture and prepare the surface |
| Rust-Oleum metallic silver | Metallic base layer |
| Dupli-Color Metalcast Anodized Coating - Red | Final translucent metallic-red color |
| Rust-Oleum Painter's Touch 2X Gloss Clear | Protective gloss clear coat |

## Development / Workshop Purchases

These were bought for Atlas development, prototyping, assembly, or future projects, but they were not all installed in the final robot:

- M3 heat-set insert / screw assortment
- perfboard assortment
- solder wick and flux
- extra MG995 and MG90S servos from multipacks
- extra potentiometers
- extra bearings and steel balls from assortments
- extra wiring and servo extension leads
- unused filament from the purchased spools

I did not include general reusable tools such as screwdrivers, soldering tools, cutters, or measuring tools.

## Procurement Cost Note

The purchase screenshots include both TTD and USD totals. Some screenshots are cropped before the order total and some orders contain multiple items, so this is not an exact final-build cost.

From the screenshots where the order total is visible:

- **TTD visible orders:** TTD **1,290.93**
- Using a representative mid-August 2026 rate of about **0.145 USD per TTD**, that is about **US$187.18**
- **USD visible orders:** **US$26.84**
- **Partial documented procurement total:** about **US$214.02**

This number is a procurement subtotal, not the cost of only the parts installed on Atlas. Some of the material was left over for future projects, and some purchases are missing because the screenshot did not show a usable total.

<details>
<summary><b>Visible order totals used for the subtotal</b></summary>

| Order date | Visible purchase(s) | Order total |
|---|---|---:|
| Aug 30, 2026 | Gloss clear + metallic silver paint | TTD 139.34 |
| Aug 18, 2026 | Precision steel-ball assortment | TTD 66.70 |
| Aug 13, 2026 | Dupli-Color Metalcast red | TTD 149.29 |
| Aug 9, 2026 | Anycubic white PLA bundle | TTD 200.05 |
| Aug 7, 2026 | 22 AWG wire assortment | TTD 113.84 |
| Aug 6, 2026 | Anycubic black PLA | TTD 94.76 |
| Jul 15, 2026 | F688-2RS flanged bearings | TTD 89.94 |
| Jul 8, 2026 | 5 V, 10 A power supply | TTD 153.99 |
| Jul 8, 2026 | Arduino Nano boards + PCA9685 modules | TTD 156.28 |
| Jul 4, 2026 | MG995 servo pack | TTD 126.74 |
| Jun 30, 2026 | Perfboard assortment | US$10.74 |
| Jun 30, 2026 | Heat-set insert / screw assortment | US$16.10 |

The MG90S/potentiometer purchase, servo-extension leads, and soldering consumables did not show a usable order total in the screenshots, so I left them out of the subtotal.

</details>

## Notes

- The final arm uses a **5 V, 10 A** external supply instead of the lower-current supply I considered earlier.
- The final base uses the printed slew-bearing redesign with six steel balls.
- I used "As required" where I did not have a final installed count instead of guessing.

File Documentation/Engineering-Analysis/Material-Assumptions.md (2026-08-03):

# Atlas V1 Material Properties

This document records the material data used for the preliminary engineering analysis of the 3D-printed Atlas V1 components.

## Material Identification

| Item | Specification |
|---|---|
| Manufacturer | Anycubic |
| Material | PLA |
| Technical document | Anycubic PLA TDS |
| TDS version | 3.0 |
| SolidWorks model | Linear Elastic Isotropic |
| Intended use | Preliminary mass and structural analysis |

## Manufacturer-Provided Physical Properties

| Property | Test Method | Typical Value |
|---|---|---:|
| Density | ISO 1183 at 23°C | 1.24 g/cm³ |
| Melt index | ISO 1133 | 5.7 ± 0.67 g/10 min |
| Moisture content | ISO 787-2 | 0.26% |

## Manufacturer-Provided Mechanical Properties

| Property | Orientation | Test Method | Typical Value |
|---|---|---|---:|
| Tensile strength | X-Y | ISO 527 | 48 ± 5 MPa |
| Tensile strength | Z | ISO 527 | 28 ± 2.4 MPa |
| Young's modulus | X-Y | ISO 527 | 2534 ± 85 MPa |
| Elongation at break | X-Y | ISO 527 | 8 ± 1% |
| Bending strength | X-Y | ISO 178 | 90 ± 3 MPa |
| Bending modulus | X-Y | ISO 178 | 3360 ± 100 MPa |
| Izod impact strength | X-Y | ISO 179 | 22 ± 1 kJ/m² |

## Manufacturer-Provided Thermal Properties

| Property | Typical Value |
|---|---:|
| Glass-transition temperature | 61.2°C |
| Melting temperature | 166°C |
| Crystallization temperature | 114°C |
| Vicat softening temperature | 55°C |
| Heat-deflection temperature | 54°C at 0.45 MPa |

## Values Entered in SolidWorks

| SolidWorks Property | Entered Value | Source |
|---|---:|---|
| Elastic modulus | 2534 MPa | Anycubic TDS V3.0 |
| Mass density | 1240 kg/m³ | Anycubic TDS V3.0 |
| Tensile strength | 48 MPa | Anycubic TDS V3.0 |


## Properties Not Provided by Anycubic

The TDS does not provide:

- Poisson's ratio
- shear modulus
- yield strength
- compressive strength
- thermal expansion coefficient
- thermal conductivity
- specific heat

## Material Density Verification

The custom Anycubic PLA material was temporarily assigned to the Atlas V1 base housing to verify the entered density.

| Property | SolidWorks Result |
|---|---:|
| Assigned density | 1.24 g/cm³ |
| Model volume | 535,753.64 mm³ |
| Calculated solid-model mass | 664.33 g |

The calculated value agrees with the expected relationship between model volume and the manufacturer-provided density.

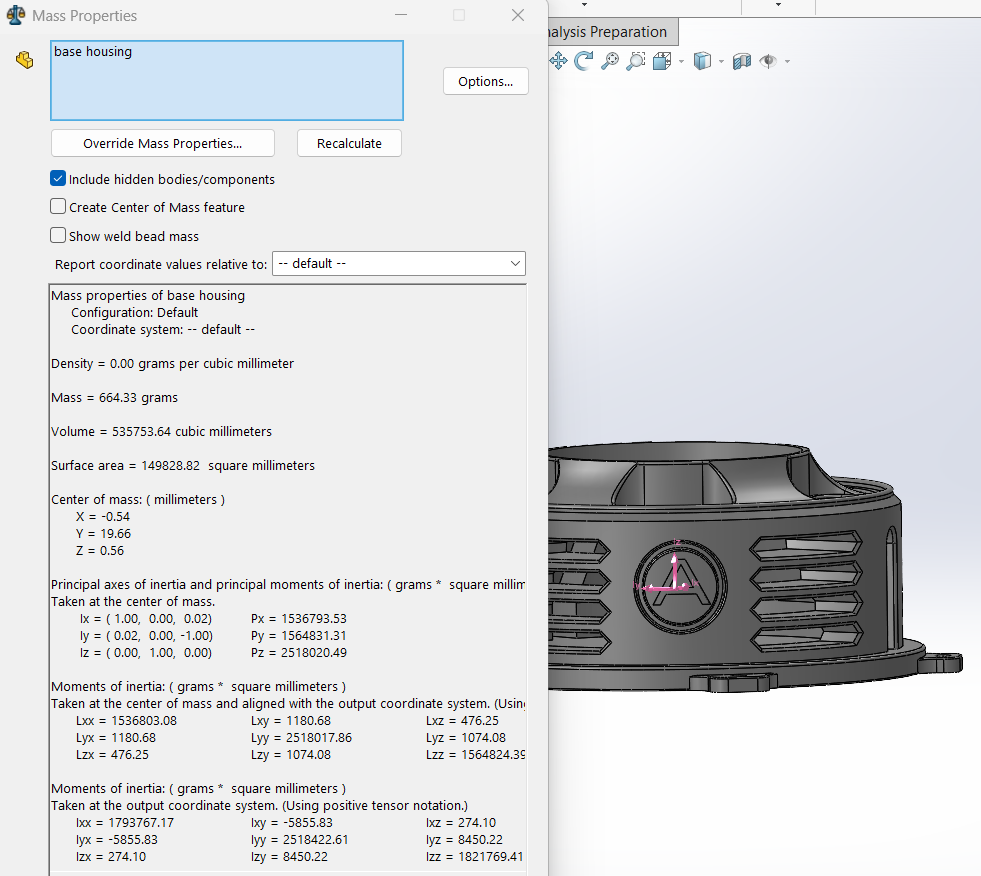
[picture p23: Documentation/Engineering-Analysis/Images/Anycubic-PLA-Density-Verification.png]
Anycubic PLA density verification


The SolidWorks result assumes that all modeled material regions are fully dense. Actual printed mass may be lower because slicer-generated infill is not represented in the CAD mass calculation. Bambu Studio estimates and physical measurements will therefore be recorded separately for load calculations and validation.

Any additional values required for simulation will be obtained from separately cited technical sources and clearly identified as engineering assumptions rather than manufacturer-provided properties.

## Analysis Limitations

The SolidWorks material model treats PLA as homogeneous and isotropic. FDM-printed components are anisotropic, and their performance depends on print orientation, layer adhesion, wall count, infill, temperature, moisture, and print quality.

Anycubic reports an X-Y tensile strength of 48 ± 5 MPa and a Z-direction tensile strength of 28 ± 2.4 MPa. Therefore, print orientation must be considered when interpreting simulation results.

The Anycubic TDS also states that its values are intended for comparison rather than final design specifications. The numerical analysis will therefore be treated as preliminary and will later be validated through physical testing.

## Reference
Anycubic. *Anycubic PLA Technical Data Sheet*, Version 3.0.  
   [View the manufacturer technical data sheet](References/Anycubic-PLA-TDS-v3.0.pdf)

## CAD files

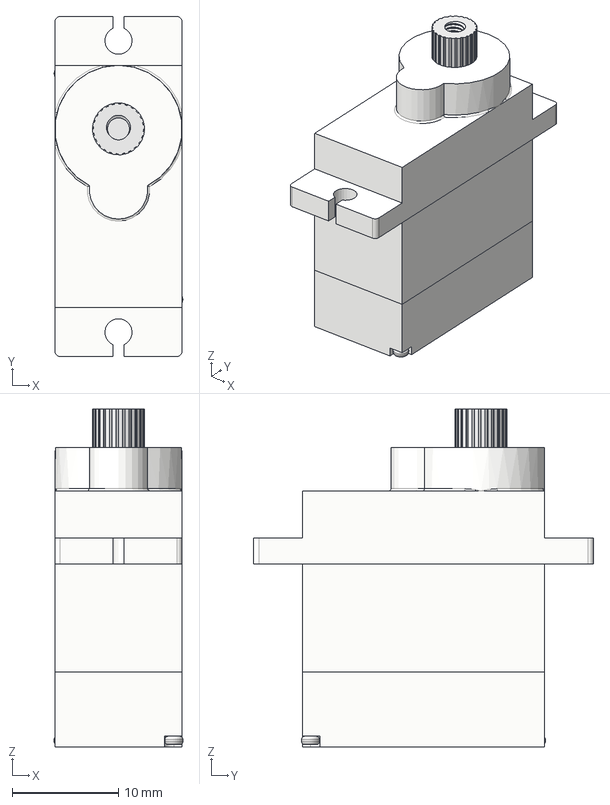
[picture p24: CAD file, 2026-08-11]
CAD/Reference_Components/MG90S/Assembly Micro Servo MG90S.step
12.1 x 32.1 x 31.8 mm
Micro Motor
Middel Part
Buttom Part
Shaft B
Gear C
Gear B
Gear A
Main Shaft with Gear
Upper Part
Main Screw x 2

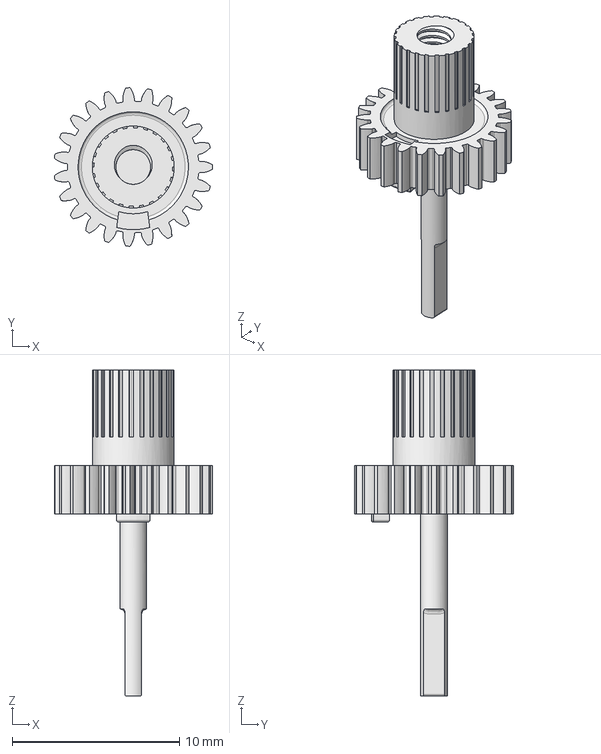
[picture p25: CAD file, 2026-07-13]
Atlas-V1/CAD/Reference_Components/MG90S/Main Shaft with Gear.step
9.47 x 9.49 x 19.5 mm

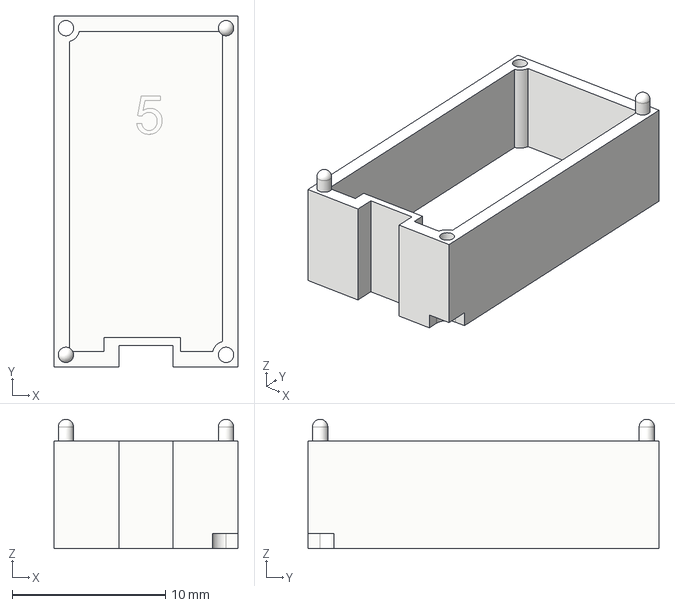
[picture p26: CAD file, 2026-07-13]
Atlas-V1/CAD/Reference_Components/MG90S/Buttom Part.step
12.0 x 22.9 x 8.44 mm

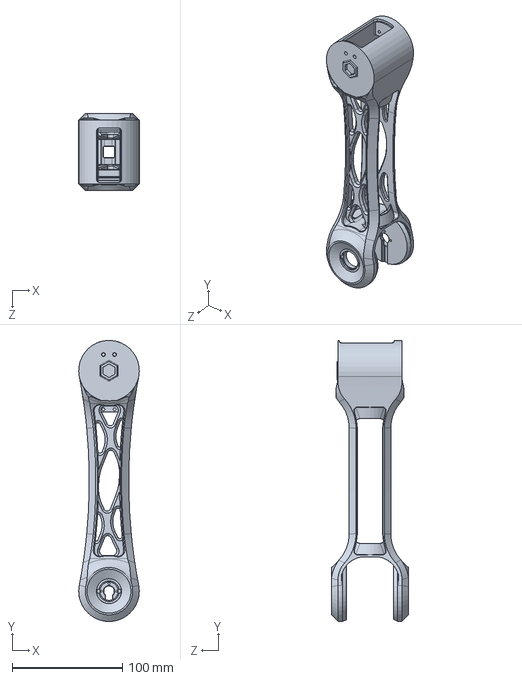
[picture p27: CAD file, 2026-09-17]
CAD/Final-Package/Atlas-V1-Upper-Arm.SLDPRT
55.0 x 254.9 x 70.0 mm

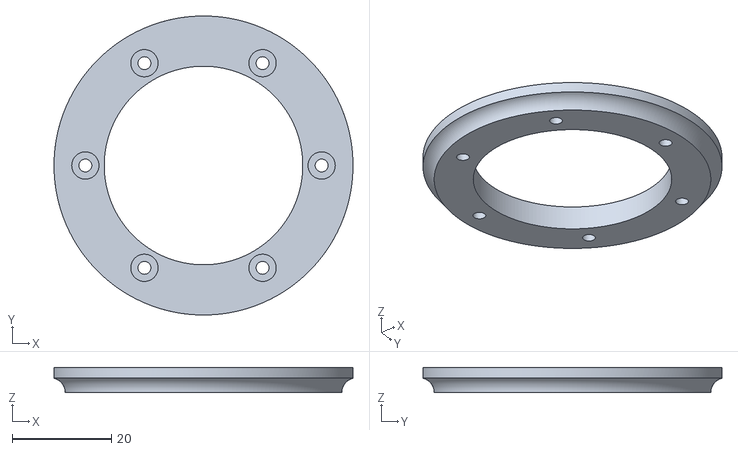
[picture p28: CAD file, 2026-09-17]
CAD/Slew-Bearing/Upper Inner Race.stl
60.2 x 60.2 x 5.10

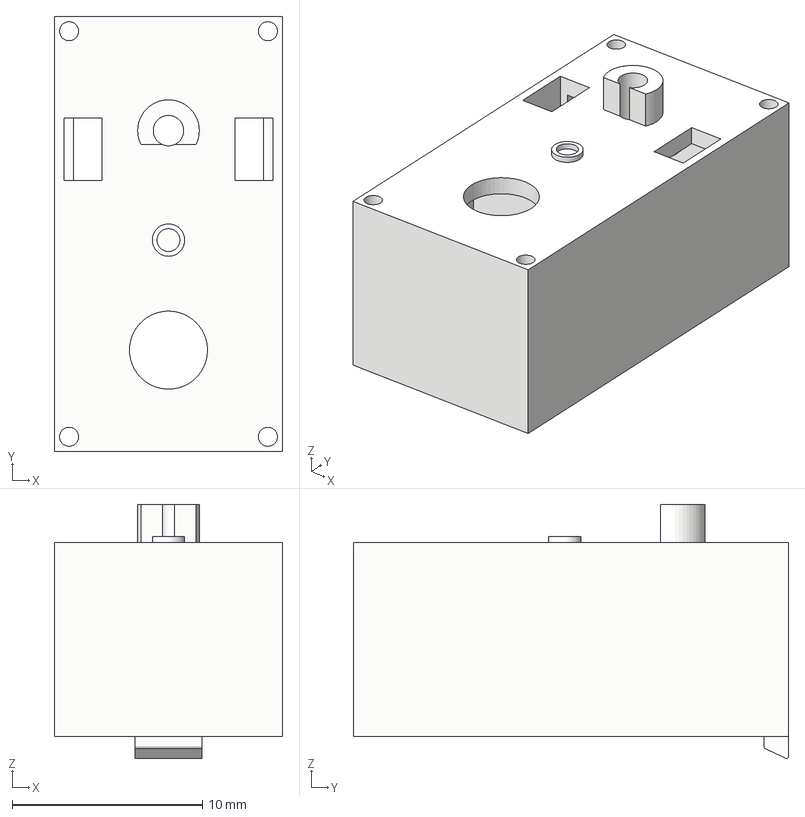
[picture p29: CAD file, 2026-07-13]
Atlas-V1/CAD/Reference_Components/MG90S/Middel Part.step
12.0 x 22.9 x 13.3 mm

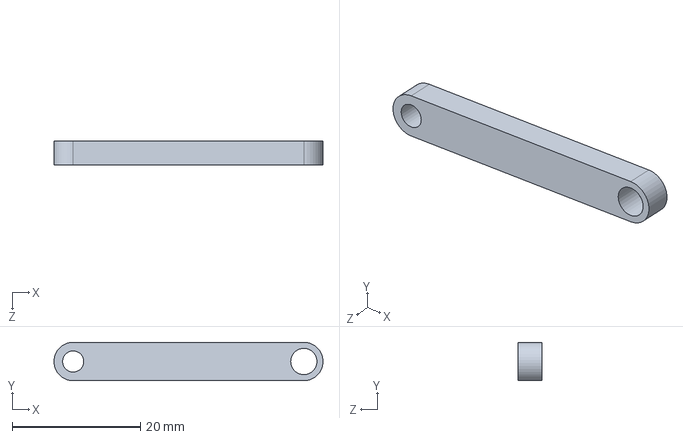
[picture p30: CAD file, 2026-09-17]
CAD/Final-Package/gripper link1.SLDPRT
42.0 x 6.00 x 3.80 mm

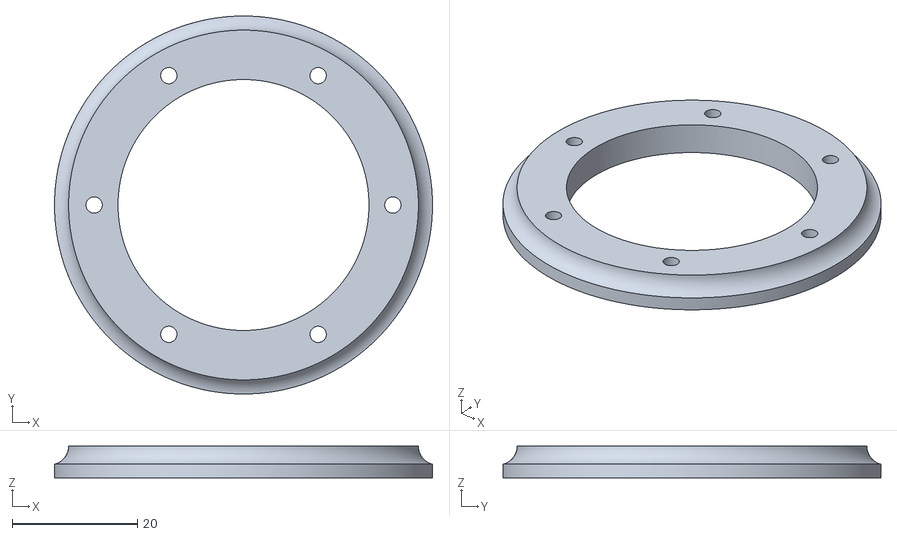
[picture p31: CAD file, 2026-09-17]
CAD/Slew-Bearing/Lower Inner Race.stl
60.2 x 60.2 x 5.10

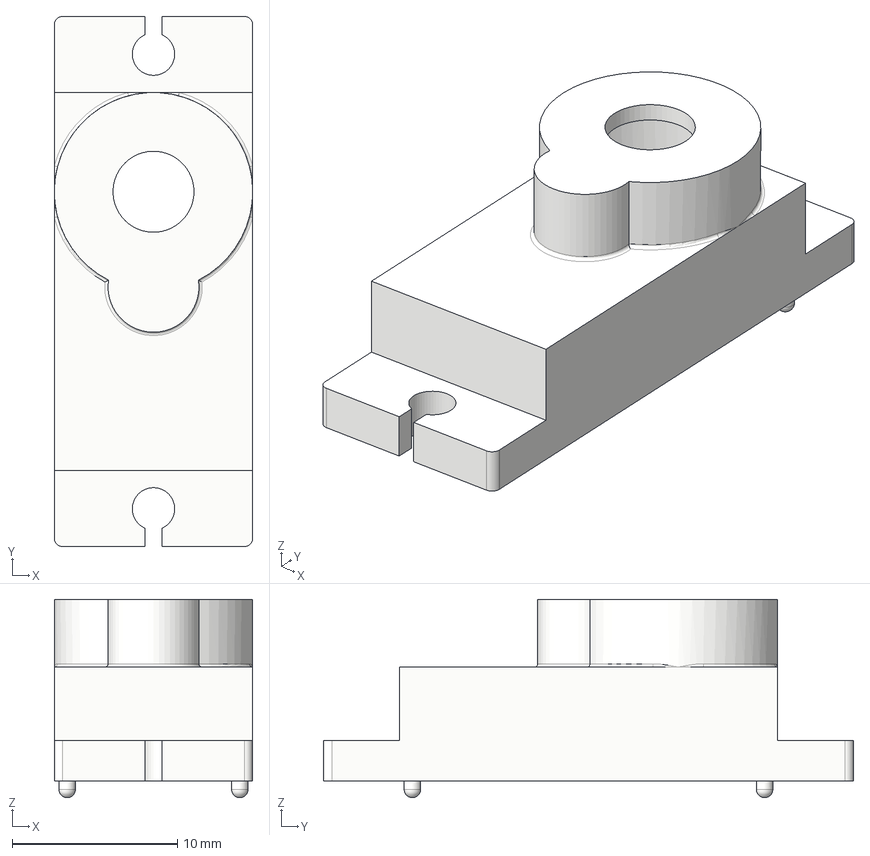
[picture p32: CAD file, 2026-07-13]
Atlas-V1/CAD/Reference_Components/MG90S/Upper Part.step
12.0 x 32.1 x 12.0 mm

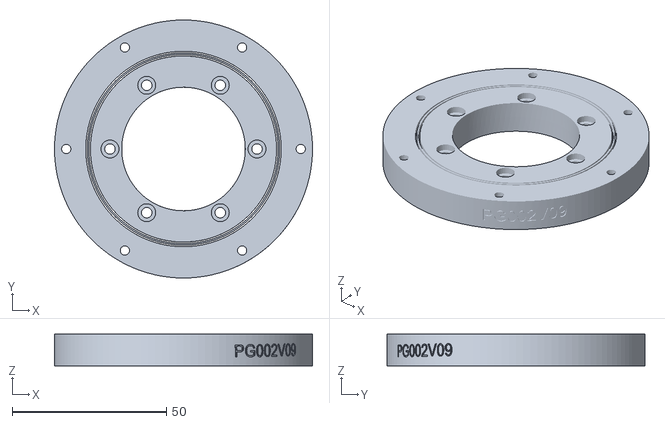
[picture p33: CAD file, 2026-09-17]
CAD/Slew-Bearing/Parametric+Slew+Bearing+v9.stl
83.5 x 83.5 x 10.2

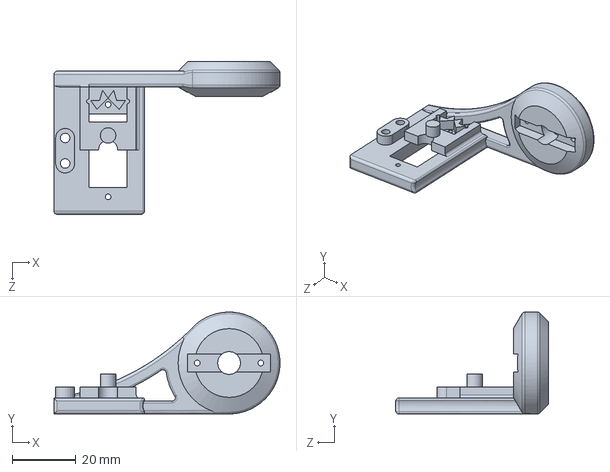
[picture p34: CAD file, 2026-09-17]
CAD/Final-Package/robotic gripper wrist.SLDPRT
71.0 x 32.0 x 48.0 mm

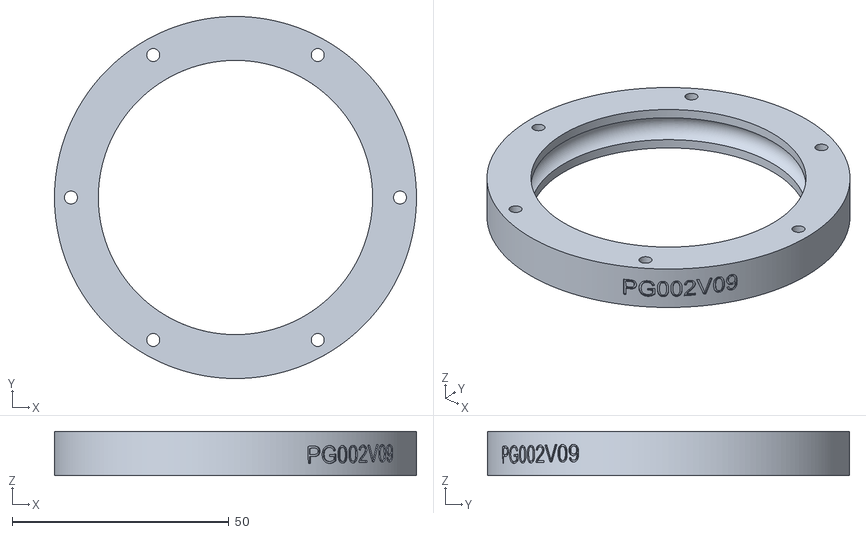
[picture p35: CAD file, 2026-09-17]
CAD/Slew-Bearing/Outer Race.stl
83.5 x 83.5 x 10.2

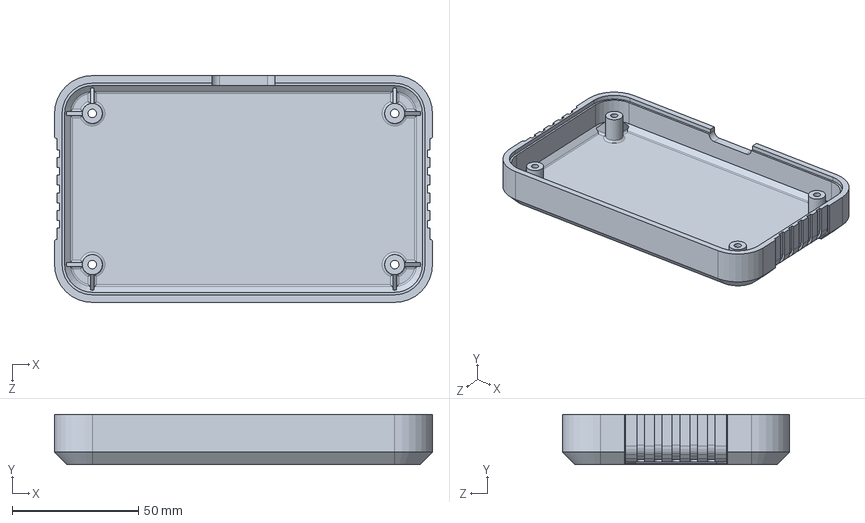
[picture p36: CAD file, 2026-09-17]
CAD/Final-Package/controller bottom.SLDPRT
150.0 x 20.0 x 90.0 mm

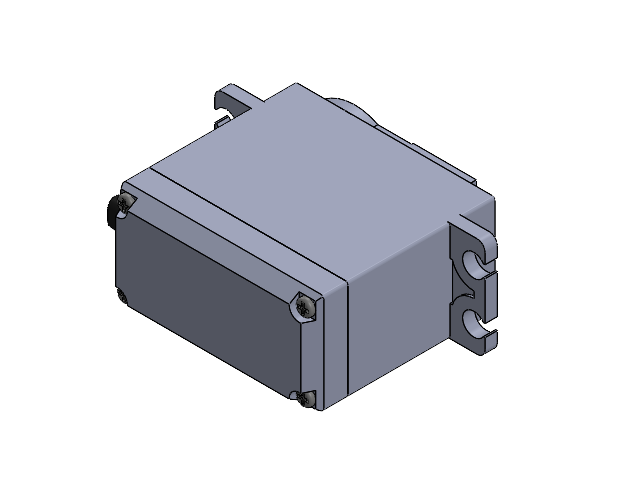
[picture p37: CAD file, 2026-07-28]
CAD/Reference_Components/MG995/MG995.SLDASM
2025-08-31-20-26-44-017.step
2025-08-31-19-50-55-859-0.step
2025-08-31-19-50-55-854.step
2025-08-31-20-05-50-383.step
2025-08-31-20-16-01-802.step

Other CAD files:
CAD/Final-Package/v3 assembly.SLDASM
CAD/Final-Package/AJM-01 → Atlas Joint Module (MG995)final.SLDPRT
CAD/Final-Package/Atlas-V1-Base-Housing bottom.SLDPRT.SLDPRT
CAD/Final-Package/Atlas-V1-Base-Housing bottom.STL
CAD/Final-Package/Atlas-V1-Base-Housing top.SLDPRT.SLDPRT
CAD/Final-Package/Atlas-V1-Base-Housing top.STL
CAD/Final-Package/Atlas-V1-Forearm edit v2.SLDPRT
CAD/Final-Package/Atlas-V1-Forearm edit v2.STL
CAD/Final-Package/Atlas-V1-Shoulder-Mount-Left.SLDPRT
CAD/Final-Package/Atlas-V1-Shoulder-Mount-Left.STL
CAD/Final-Package/Atlas-V1-Shoulder-Mount-Right.SLDPRT
CAD/Final-Package/Atlas-V1-Shoulder-Mount-Right.STL
CAD/Final-Package/Atlas-V1-Upper-Arm.STL
CAD/Final-Package/base housing.SLDPRT
CAD/Final-Package/bearing holder link 2.SLDPRT
CAD/Final-Package/bearing holder.SLDPRT
CAD/Final-Package/bearing holder.STL
CAD/Final-Package/bearing holder2.SLDPRT
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

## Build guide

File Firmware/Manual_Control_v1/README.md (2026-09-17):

# Manual Control v1 — Development Archive

Manual Control v1 was the first integrated potentiometer-based controller used during Project Atlas mechanical and electronics testing.

It demonstrated the core control path:

**Potentiometers → Arduino Nano → I2C → PCA9685 → Servos**

The sketch was useful for validating joint motion, servo direction, wiring, range of motion, and overall system integration before the final controller was completed.

## Status

**Archived development firmware.**

The completed V1 controller is now documented in:

[`../Final_Control/Atlas_Final_Control.ino`](../Final_Control/Atlas_Final_Control.ino)

The final sketch adds input averaging, a deadband, and 16×2 LCD joint/angle feedback while retaining the same basic manual-control architecture.

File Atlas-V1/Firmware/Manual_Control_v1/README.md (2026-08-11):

# Manual Control v1

## Purpose

Initial firmware used to validate MG90S servo operation using a single 10k potentiometer.

## Hardware

- Arduino Uno
- MG90S Servo
- 10k Potentiometer

## Features

- Reads analog input from potentiometer.
- Maps input to servo angle.
- Controls one MG90S servo.

## Status
 Validated

## Future Improvements

- Support multiple servos
- External power supply
- Motion recording
- Playback mode

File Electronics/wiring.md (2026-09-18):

# Atlas V1 Wiring

This page matches the final manual-control firmware and electronics setup.

## Arduino Nano - PCA9685

| Arduino Nano | PCA9685 | Function |
|---|---|---|
| 5V | VCC | PCA9685 logic power |
| GND | GND | Common reference |
| A4 | SDA | I2C data |
| A5 | SCL | I2C clock |

## I2C LCD

The 16x2 I2C LCD shares the same I2C bus:

| LCD | Arduino Nano | Function |
|---|---|---|
| VCC | 5V | LCD power |
| GND | GND | Common ground |
| SDA | A4 | I2C data |
| SCL | A5 | I2C clock |

## External Servo Power

The five servos are powered from a regulated **5 V, 10 A** external supply through the PCA9685 servo rail.

| Power supply | PCA9685 |
|---|---|
| +5 V | V+ screw terminal |
| GND | GND screw terminal |

The Arduino Nano is powered through USB. The Nano, PCA9685, LCD, and external supply all share a common ground.

## Potentiometer Inputs

| Analog pin | Firmware label |
|---|---|
| A0 | BASE |
| A1 | ELBOW |
| A2 | WRIST |
| A3 | PIVOT |
| A6 | JAWS |

Each potentiometer is wired with:

- one outer terminal - 5 V
- one outer terminal - GND
- center wiper - assigned analog input

## PCA9685 Servo Channels

| PCA9685 channel | Firmware label |
|---|---|
| PWM0 | BASE |
| PWM1 | ELBOW |
| PWM2 | WRIST |
| PWM3 | PIVOT |
| PWM4 | JAWS |

## Servo Connector Orientation

Each servo connects to the PCA9685 with:

- signal - PWM
- positive - V+
- ground - GND

I used servo extension leads and 22 AWG flexible wire where needed to route the wiring through the arm and controller.

## Power / Wiring Checks

Before applying power:

- verify the external supply is regulated to 5 V
- verify V+ and GND polarity at the PCA9685
- confirm the Nano and external supply share ground
- confirm the LCD and PCA9685 are on the correct I2C lines
- confirm servo connectors are oriented correctly
- do not power the servo rail from the Nano's 5 V pin

## Reference Diagrams

- [Arduino Nano and potentiometer wiring](./Arduino%20Nano%20and%20potentiometer%20wiring.png)
- [PCA9685 servo wiring](./PCA9685%20servo%20wiring.png)

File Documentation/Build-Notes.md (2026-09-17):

# Atlas V1 Build Notes

These are the main manufacturing and integration choices I used for the completed Atlas V1 prototype.

## Manufacturing Approach

I designed Atlas around FDM 3D printing so I could make changes quickly after testing the real parts.

The final CAD package includes the SolidWorks parts and assembly files along with STL exports for the printable parts. I kept the design modular instead of making one large shell so individual parts could be reprinted or changed without rebuilding everything.

The main things I considered were:

- printability and reducing support material
- access to servos and fasteners
- joint clearance
- cable-routing space
- stiffness without adding unnecessary mass
- replaceable covers and subcomponents

## Base and Slew Bearing

During testing, I found that the rotating base could tilt under the weight of the arm. Relying mainly on the servo output area was not enough to support the structure.

I redesigned the base around a printed slew bearing so the mechanical support and servo actuation were separated. The final bearing uses **six steel balls**.

The slew-bearing folder includes the race and cage geometry along with the Fusion 360 outer-race source.

## Arm and Joint Revisions

Assembly and testing also exposed several problems that led to CAD changes:

- forearm interference and restricted motion
- wire pinching and limited routing space
- servo-horn interference
- difficult access to some joints
- wrist and gripper packaging

Because of this, the final package includes revised forearm, base, servo-interface, bearing-holder, controller, and end-effector parts instead of the first printable versions.

## Electronics Integration

The final control setup uses:

- Arduino Nano
- PCA9685 servo PWM driver
- five potentiometer inputs
- five servo channels
- 16x2 I2C LCD
- regulated external 5 V, 10 A servo supply

The Nano, PCA9685, LCD, and external supply share a common ground. Servo power comes from the external supply through the PCA9685 servo rail, not directly from the Nano.

See [Electronics](../Electronics/) for the wiring details.

## Controller Enclosure

I built a separate printed controller enclosure for the manual controls and display.

The final controller includes:

- five rotary potentiometers
- 16x2 LCD
- printed top, bottom, and control-panel parts
- wiring between the controller and the arm electronics

Keeping the controls separate made the arm easier to work on and kept the user interface from being built into the base.

## Firmware Behavior

The final firmware:

- averages 8 analog samples for each potentiometer reading
- maps each input to a 0-180 degree servo command
- uses a 2 degree deadband to reduce unnecessary updates
- commands the PCA9685 at 50 Hz
- updates the LCD with the joint name and angle when the input changes enough
- provides serial output for debugging

See [Firmware](../Firmware/) for the final sketch.

## Surface Preparation and Finish

I wanted the final arm to look finished instead of leaving the PLA raw, so I used a layered paint process:

1. Rust-Oleum 2-in-1 Filler & Sandable Primer
2. Rust-Oleum metallic silver base
3. Dupli-Color Metalcast red anodized coating
4. Rust-Oleum Painter's Touch 2X Gloss Clear

The silver layer gives the translucent red Metalcast something reflective underneath it, and the clear coat protects the finish and gives it the final gloss.

<p align="center">
  Completed metallic-red Project Atlas arm
</p>

## Final Build Status

Atlas V1 is complete as a functional physical prototype with integrated mechanics, electronics, firmware, user controls, and surface finishing.

I have not listed payload, backlash, accuracy, or repeatability values because I did not run controlled tests for those measurements yet.

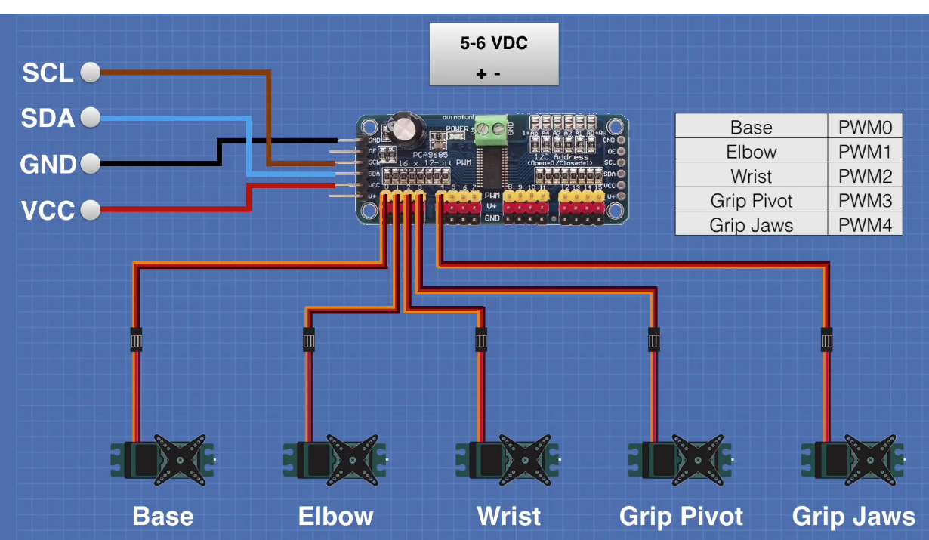
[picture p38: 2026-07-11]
Atlas-V1/Electronics/PCA9685 servo wiring.png

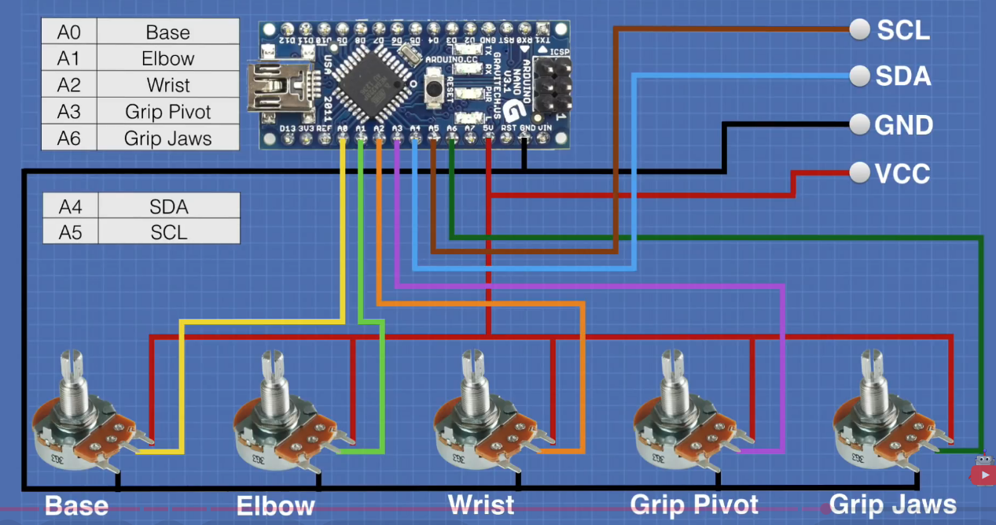
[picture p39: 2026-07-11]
Electronics/Arduino Nano and potentiometer wiring.png

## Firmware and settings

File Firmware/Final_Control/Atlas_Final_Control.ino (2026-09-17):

#include <Wire.h>
#include <Adafruit_PWMServoDriver.h>
#include <hd44780.h>
#include <hd44780ioClass/hd44780_I2Cexp.h>

// ----------------------
// PCA9685 settings
// ----------------------

#define MIN_PULSE_WIDTH 650
#define MAX_PULSE_WIDTH 2350
#define FREQUENCY 50

Adafruit_PWMServoDriver pwm = Adafruit_PWMServoDriver();

// ----------------------
// LCD
// ----------------------

hd44780_I2Cexp lcd;

// ----------------------
// Potentiometer inputs
// ----------------------

const int controlBase  = A0;
const int controlElbow = A1;
const int controlWrist = A2;
const int controlPivot = A3;
const int controlJaws  = A6;

// ----------------------
// PCA9685 servo channels
// ----------------------

const int motorBase  = 0;
const int motorElbow = 1;
const int motorWrist = 2;
const int motorPivot = 3;
const int motorJaws  = 4;

// ----------------------
// Last servo positions
// ----------------------

int lastBase  = -100;
int lastElbow = -100;
int lastWrist = -100;
int lastPivot = -100;
int lastJaws  = -100;

// Ignore changes smaller than this
const int DEADBAND = 2;

// ----------------------
// Setup
// ----------------------

void setup()
{
  Serial.begin(9600);

  // Start PCA9685
  pwm.begin();
  pwm.setPWMFreq(FREQUENCY);

  delay(500);

  // Start LCD
  int status = lcd.begin(16, 2);

  if (status)
  {
    Serial.println("LCD initialization failed");
    while (1);
  }

  lcd.clear();

  lcd.setCursor(0, 0);
  lcd.print("PROJECT ATLAS");

  lcd.setCursor(0, 1);
  lcd.print("SYSTEM READY");

  delay(2000);

  lcd.clear();
}

// ----------------------
// Servo control function
// ----------------------

void moveMotorDeg(int moveDegree, int motorOut)
{
  int pulseWide;

  pulseWide = map(
    moveDegree,
    0,
    180,
    MIN_PULSE_WIDTH,
    MAX_PULSE_WIDTH
  );

  int pulseWidth = int(
    float(pulseWide) / 1000000.0 * FREQUENCY * 4096
  );

  pwm.setPWM(motorOut, 0, pulseWidth);
}

// ----------------------
// Read + smooth potentiometer
// ----------------------

int getDegree(int controlIn)
{
  long total = 0;

  // Average 8 readings
  for (int i = 0; i < 8; i++)
  {
    total += analogRead(controlIn);
    delayMicroseconds(200);
  }

  int potValue = total / 8;

  int servoDegree = map(
    potValue,
    0,
    1023,
    0,
    180
  );

  return servoDegree;
}

// ----------------------
// LCD update
// ----------------------

void displayJoint(const char* jointName, int angle)
{
  lcd.clear();

  lcd.setCursor(0, 0);
  lcd.print("JOINT:");
  lcd.print(jointName);

  lcd.setCursor(0, 1);
  lcd.print("ANGLE: ");
  lcd.print(angle);
  lcd.print((char)223);  // degree symbol
}

// ----------------------
// Update one servo
// ----------------------

void updateServo(
  int potPin,
  int servoChannel,
  int &lastAngle,
  const char* jointName
)
{
  int newAngle = getDegree(potPin);

  // Only move if change is significant
  if (abs(newAngle - lastAngle) >= DEADBAND)
  {
    moveMotorDeg(newAngle, servoChannel);

    lastAngle = newAngle;

    displayJoint(jointName, newAngle);

    Serial.print(jointName);
    Serial.print(": ");
    Serial.println(newAngle);
  }
}

// ----------------------
// Main loop
// ----------------------

void loop()
{
  updateServo(
    controlBase,
    motorBase,
    lastBase,
    "BASE"
  );

  updateServo(
    controlElbow,
    motorElbow,
    lastElbow,
    "ELBOW"
  );

  updateServo(
    controlWrist,
    motorWrist,
    lastWrist,
    "WRIST"
  );

  updateServo(
    controlPivot,
    motorPivot,
    lastPivot,
    "PIVOT"
  );

  updateServo(
    controlJaws,
    motorJaws,
    lastJaws,
    "JAWS"
  );

  delay(20);
}

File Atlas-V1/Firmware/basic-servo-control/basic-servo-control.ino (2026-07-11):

/*
  Project Atlas
  Basic 5-DOF Servo Controller

  Uses:
  - Arduino Nano
  - PCA9685 PWM servo controller
  - Five potentiometers
  - Five servos

  Based on the DroneBot Workshop robot arm controller example.
  Adapted for Project Atlas hardware testing.

  Author: Ethan Tsui
  Date: July 10, 2026
*/

#include <Wire.h>
#include <Adafruit_PWMServoDriver.h>

#define MIN_PULSE_WIDTH 650
#define MAX_PULSE_WIDTH 2350
#define FREQUENCY 50

Adafruit_PWMServoDriver pwm = Adafruit_PWMServoDriver();

// Potentiometer inputs
int controlBase = A0;
int controlElbow = A1;
int controlWrist = A2;
int controlPivot = A3;
int controlJaws = A6;

// PCA9685 servo channels
int motorBase = 0;
int motorElbow = 1;
int motorWrist = 2;
int motorPivot = 3;
int motorJaws = 4;

// Motor position variables
int mtrDegreeBase;
int mtrDegreeElbow;
int mtrDegreeWrist;
int mtrDegreePivot;
int mtrDegreeJaws;

void setup()
{
  pwm.begin();
  pwm.setPWMFreq(FREQUENCY);
}

void moveMotorDeg(int moveDegree, int motorOut)
{
  int pulseWide;
  int pulseWidth;

  pulseWide = map(
    moveDegree,
    0,
    180,
    MIN_PULSE_WIDTH,
    MAX_PULSE_WIDTH
  );

  pulseWidth = int(
    float(pulseWide) / 1000000 * FREQUENCY * 4096
  );

  pwm.setPWM(motorOut, 0, pulseWidth);
}

int getDegree(int controlIn)
{
  int potVal;
  int servoDegree;

  potVal = analogRead(controlIn);
  servoDegree = map(potVal, 0, 1023, 0, 180);

  return servoDegree;
}

void loop()
{
  mtrDegreeBase = getDegree(controlBase);
  moveMotorDeg(mtrDegreeBase, motorBase);

  mtrDegreeElbow = getDegree(controlElbow);
  moveMotorDeg(mtrDegreeElbow, motorElbow);

  mtrDegreeWrist = getDegree(controlWrist);
  moveMotorDeg(mtrDegreeWrist, motorWrist);

  mtrDegreePivot = getDegree(controlPivot);
  moveMotorDeg(mtrDegreePivot, motorPivot);

  mtrDegreeJaws = getDegree(controlJaws);
  moveMotorDeg(mtrDegreeJaws, motorJaws);

  delay(20);
}

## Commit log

2026-07-01 Create servo
2026-07-13 Reorganize repository for Atlas V1
    Moved all CAD, firmware, electronics, and documentation into the Atlas-V1 directory to establish a versioned project structure for future Atlas iterations.
    [Buttom Part.step, Main Shaft with Gear.step, Middel Part.step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]
2026-07-27 Create Final-Assembly
2026-07-28 Create CAD source files folder
2026-08-03 Add Atlas V1 static shoulder torque analysis
2026-08-11 Remove outdated Atlas-V1 folder structure structure
    [AJM-01 → Atlas Joint Module (MG995)final.SLDPRT, Assembly Micro Servo MG90S.SLDASM, Assembly Micro Servo MG90S.step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]
2026-08-11 Revert "Remove outdated Atlas-V1 folder structure structure"
    This reverts commit f18731d13171832a161b3c198bbf3a68fb1fff4a.
    [AJM-01 → Atlas Joint Module (MG995)final.SLDPRT, Assembly Micro Servo MG90S.SLDASM, Assembly Micro Servo MG90S.step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]
2026-08-11 Reorganize Project Atlas repository
    [AJM-01 → Atlas Joint Module (MG995)final.SLDPRT, Assembly Micro Servo MG90S.SLDASM, Assembly Micro Servo MG90S.step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]
2026-09-17 Add NFC portfolio landing page
2026-09-17 Update CAD documentation for final V1 package
2026-09-17 Replace preliminary BOM with final build BOM
2026-09-17 Update wiring for final controller and LCD
2026-09-17 Add final CAD package manifest
2026-09-17 Link final CAD manifest
2026-09-17 Create final CAD upload folder
2026-09-17 Create slew bearing upload folder
2026-09-17 Label legacy CAD source folder
2026-09-17 Add final Project Atlas CAD package
    [AJM-01 → Atlas Joint Module (MG995)final.SLDPRT, Atlas-V1-Base-Housing bottom.SLDPRT.SLDPRT, Atlas-V1-Base-Housing bottom.STL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]
2026-09-17 Remove placeholder from populated final CAD folder
2026-09-17 Remove placeholder from populated slew-bearing folder
2026-09-17 Remove legacy CAD source placeholder
2026-09-17 Remove duplicate legacy CAD source
    [AJM-01 → Atlas Joint Module (MG995)final.SLDPRT]
2026-09-17 Remove legacy CAD source documentation
2026-09-17 Simplify final CAD documentation
2026-09-17 Finalize CAD package manifest
2026-09-17 Make CAD documentation more personal
2026-09-17 Make BOM tone more natural
2026-09-17 Clean up wiring documentation style
2026-09-17 Clean up CAD manifest style
2026-09-17 Update final Atlas CAD screenshots
2026-09-18 Update extended final CAD view
2026-09-18 Update final CAD view gallery
2026-09-18 Add final CAD view to design evolution
2026-09-18 Update electronics wiring documentation
